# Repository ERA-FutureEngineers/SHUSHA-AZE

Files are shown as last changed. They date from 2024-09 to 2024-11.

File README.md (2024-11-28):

# SHUSHA-AZE 2024
 ## Topics

* [Electronic-Components](#components)
   * [Pixy2.1 cam](#components)
   * [MPU6050](#Gyro)
   * [Servo](#servo)
   * [Driver L298N and Dc motors](#driver)
   * [Ultrasonic sensors](#ultrasonics)
   * [Arduino Mega 2560 Rev3](#mega)
   * [Power Managament](#power)
* [Robot Photos](#robotphotos)
* [Performance videos](#pvideo)
* [Scheme](#scheme)
* [TeamPhoto](#tphoto)
* [Steering system](#system)
* [Logic of Codes](#code)
  * [First round logic](#code)
  * [Second round logic](#code2nd)

## Electronic-Components 
### Pixy2.1 cam  
   
pixy222

The main reason we chose the Pixy 2.1 is its high performance and real-time processing capabilities. Initially, we considered using the ESP CAM, but after discovering its limited image processing capabilities and noticeable latency, we decided to switch to the Pixy 2.1. Pixy 2.1 is a specialized image processing sensor designed for recognizing colors and tracking objects. It can also integrate with various programming platforms and is easily connectable to Arduino, Raspberry Pi, STM32, and other microcontrollers. Moreover, Pixy 2.1 can simultaneously perform multiple object recognition and tracking functions, making it highly convenient for our needs. Another advantage of this camera is its user-friendly interface. It supports numerous communication protocols, such as USB, UART, I2C, and SPI, allowing seamless integration with any microcontroller and other electronic components. Therefore, choosing Pixy 2.1 has enabled our robot to achieve more precise and faster image processing.

#### With this code measure distance

```ino
#include <Pixy2.h>
#include <Servo.h>

Servo servo_9;
long duration;
int distance;
 float knownWidth = 5.0;
 float focalLength = 218; 
 int colorX = 0;
Pixy2 pixy;

void setup() {
  servo_9.attach(2);
  Serial.begin(9600);
  pixy.init();
}

void loop() {
  pixy.ccc.getBlocks();
  
  if (pixy.ccc.numBlocks) {
    int objectWidth = pixy.ccc.blocks[0].m_width; 
    int colorX = pixy.ccc.blocks[0].m_x;
    
    float distance = (knownWidth * focalLength) / objectWidth;
    Serial.println(distance);
    delay(50);
  }
}
```

#### Passing cubes with pixy

```ino
        pixy.ccc.getBlocks();
    bool greenDetected = false, redDetected = false;  
    int colorX = 0, k = 0, j = 0, old = 0, mx = 0;
    height = 0;
    for (int i = 0; i < pixy.ccc.numBlocks; i++) {
      if(old <= (pixy.ccc.blocks[i].m_x) * (pixy.ccc.blocks[i].m_height)){
        old = (pixy.ccc.blocks[i].m_x) * (pixy.ccc.blocks[i].m_height);
        j = i;
      }
    }
      if (pixy.ccc.blocks[j].m_signature == 1) {
        greenDetected = true;
        colorX = pixy.ccc.blocks[j].m_x;
        objectWidth = pixy.ccc.blocks[j].m_width;
        height = pixy.ccc.blocks[j].m_height;
      }
      if (pixy.ccc.blocks[j].m_signature == 2) {
        redDetected = true;
        colorX = pixy.ccc.blocks[j].m_x;
        objectWidth = pixy.ccc.blocks[j].m_width;
        height = pixy.ccc.blocks[j].m_height;
      }

    distance = (knownWidth * focalLength) / objectWidth;

  if (redDetected) {
    if ((R == 1 && abs(currentAngle - targetAngle) <= 50) || L == 1) {
        updateGyroAngle();
        last_color = 2;

        if (colorX > 90) {
            servo_9.write(70);
        } else if (R == 1 && colorX < 40 && abs(currentAngle - targetAngle) >= 15) {
            servo_9.write(110);
        } else {
            servo_9.write(90);
      }
    }
  }
  else if (greenDetected) {
    if ((L == 1 && abs(currentAngle - targetAngle) <= 50) || R == 1) {
        updateGyroAngle();
        last_color = 1;

        if (colorX < 220) {
            servo_9.write(110);
        } else if (L == 1 && colorX > 270 && abs(currentAngle - targetAngle) >= 15) {
            servo_9.write(70);
        } else {
            servo_9.write(90);
        }
      }
    }
```
    
### MPU6050 

mpu222

To use the gyro sensor, we first need to include the **MPU6050.h** library in the project. This library is essential for managing the functions of the MPU6050 sensor and reading its data. 
After powering on the robot, we allocate an initial 5-second time interval to ensure the sensor operates accurately. During this time, the sensor performs proper self-calibration and minimizes potential errors. As a result, obtaining accurate data from the sensor ensures improved performance and precise control of the robot.

#### This code is for measuring degrees with gyro.
```ino
void updateGyroAngle() {
  int16_t gz;
  unsigned long currentTime = millis();
  float deltaTime = (currentTime - previousTime) / 1000.0;
  previousTime = currentTime;

  gz = gyro.getRotationZ();

  float rotationZ = (gz / 131.0) - offsetZ;
  currentAngle += rotationZ * deltaTime;

  Serial.print("Filtered Angle (Yaw): ");
  Serial.println(currentAngle);

```

#### Centering the robot with gyro
```ino
void Gyro() {
  if (currentAngle - 5 > targetAngle) {
    servo_9.write(90 - angle);
  } else if (currentAngle + 5 < targetAngle) {
    servo_9.write(90 + angle);
  } else {
    servo_9.write(90);
  }
  updateGyroAngle();
}
```

### Driver L298N and Dc motors 

driverl298n-222
dc-motors222

In our project, we used the **L298N motor driver** and two DC gear motors. This driver works well with DC motors and does not cause any issues in our project.The L298N provides an effective solution for controlling the rotation direction of the motors and delivering the required power. It helps control the motors quickly and reliably.

#### Code for turning the robot on
```ino
#define LEFT_MOTOR_PWM 5
#define RIGHT_MOTOR_PWM 6
#define LEFT_MOTOR_DIR1 14
#define LEFT_MOTOR_DIR2 15
#define RIGHT_MOTOR_DIR1 16
#define RIGHT_MOTOR_DIR2 17

void setup() {
  pinMode(LEFT_MOTOR_PWM, OUTPUT);
  pinMode(RIGHT_MOTOR_PWM, OUTPUT);
  pinMode(LEFT_MOTOR_DIR1, OUTPUT);
  pinMode(LEFT_MOTOR_DIR2, OUTPUT);
  pinMode(RIGHT_MOTOR_DIR1, OUTPUT);
  pinMode(RIGHT_MOTOR_DIR2, OUTPUT);

  moveForward(70);
}

void loop() {
}

void moveForward(int speed) {
  digitalWrite(LEFT_MOTOR_DIR1, HIGH);
  digitalWrite(LEFT_MOTOR_DIR2, LOW);
  digitalWrite(RIGHT_MOTOR_DIR1, HIGH);
  digitalWrite(RIGHT_MOTOR_DIR2, LOW);
  analogWrite(LEFT_MOTOR_PWM, speed);
  analogWrite(RIGHT_MOTOR_PWM, speed);
}
```

### Servo  

servo222

#### Servo code 

This code takes the angle from the gyroscope and uses it to keep the robot balanced with a servo.
```ino
void updateGyroAngle() {
  int16_t gz, ax, ay, az;
  unsigned long currentTime = millis();
  float deltaTime = (currentTime - previousTime) / 1000.0;
  previousTime = currentTime;

  gz = gyro.getRotationZ();

  float rotationZ = (gz / 131.0) - offsetZ;
  if(abs(rotationZ * deltaTime) >= 0.1)
  currentAngle += rotationZ * deltaTime;

  Serial.print("Filtered Angle (Yaw): ");
  Serial.println(currentAngle);
}

void Gyro() {
  if (currentAngle - 5 > targetAngle) {
    servo_9.write(90 - angle);
  } else if (currentAngle + 5 < targetAngle) {
    servo_9.write(90 + angle);
  } else {
    servo_9.write(90);
  }
  updateGyroAngle();
}
```

The turning system of our robot is implemented through the combined operation of a servo and a gyro sensor. The gyro sensor measures the robot's turning angle and direction changes during movement and sends precise data to the servo. Based on this data, the servo operates accurately, ensuring the robot's turning is executed with greater precision.

### Ultrasonic sensors 
  
ultra-s222

#### Distance measurement code
```ino
const int leftTrigPin = A6;
const int leftEchoPin = A7;
const int rightTrigPin = A0;
const int rightEchoPin = A1;

long getDistance(int trigPin, int echoPin) {
  digitalWrite(trigPin, LOW);
  delayMicroseconds(2);
  digitalWrite(trigPin, HIGH);
  delayMicroseconds(10);
  digitalWrite(trigPin, LOW);

  long duration = pulseIn(echoPin, HIGH);
  long distance = duration * 0.034 / 2;

  return distance;
}

void setup() {
  pinMode(leftTrigPin, OUTPUT);
  pinMode(leftEchoPin, INPUT);
  pinMode(rightTrigPin, OUTPUT);
  pinMode(rightEchoPin, INPUT);
  Serial.begin(9600);
}

void loop() {
  long leftDistance = getDistance(leftTrigPin, leftEchoPin);
  long rightDistance = getDistance(rightTrigPin, rightEchoPin);
  Serial.print(leftDistance);
  Serial.print(" cm, Right: ");
  Serial.print(rightDistance); 
  Serial.println(" cm");
  delay(10);
}
```

### Arduino Mega 2560 Rev3 

mega222

Initially, we used an Arduino Uno in our robot. However, as the project developed, the number of sensors increased, and the pins on the Uno were no longer sufficient. For this reason, we decided to switch to the Arduino Mega. Compared to the Uno, the Mega offers significantly more capabilities. For instance, the Uno has only 14 digital input/output pins and 6 analog input pins, whereas the Mega provides 54 digital input/output pins and 16 analog input pins. These additional pins allow for connecting more sensors. In addition, the Mega has more memory (32 KB on the Uno versus 256 KB on the Mega) and a more powerful processor. Switching to the Mega was crucial for the robot’s development, as its additional pins and higher performance make it possible to manage more complex systems. Therefore, the Arduino Mega proved to be a more suitable choice for our robot.

### Power Managament 

battery555
bat2

In our robot, we use cylindrical Lithium Polymer 3.7V 18650 rechargeable Li-ion batteries as the power source. By combining three batteries, we obtain approximately 11V of power. This voltage is connected to the motor driver, and the driver’s output provides the 5V needed for the proper operation of the sensors. Since each battery weighs only 47.5 grams, the robot remains lightweight and can move faster. These batteries offer both an efficient and practical solution.

### Robot Photos 

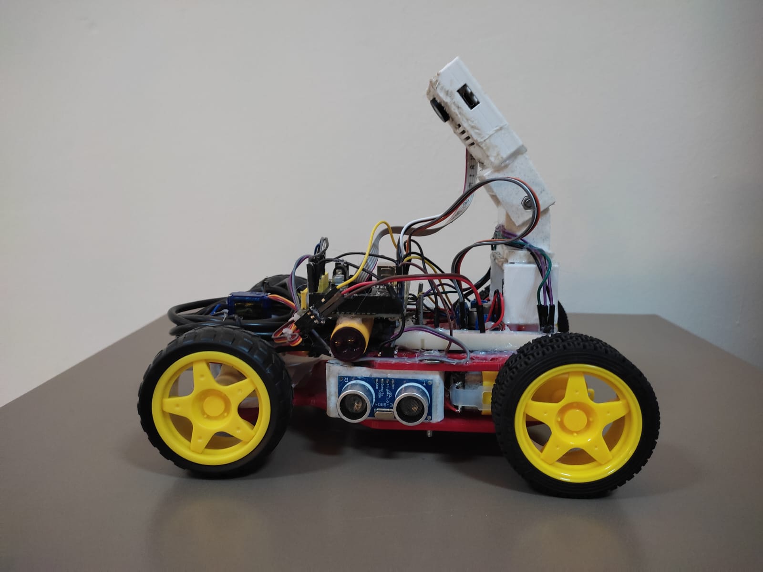
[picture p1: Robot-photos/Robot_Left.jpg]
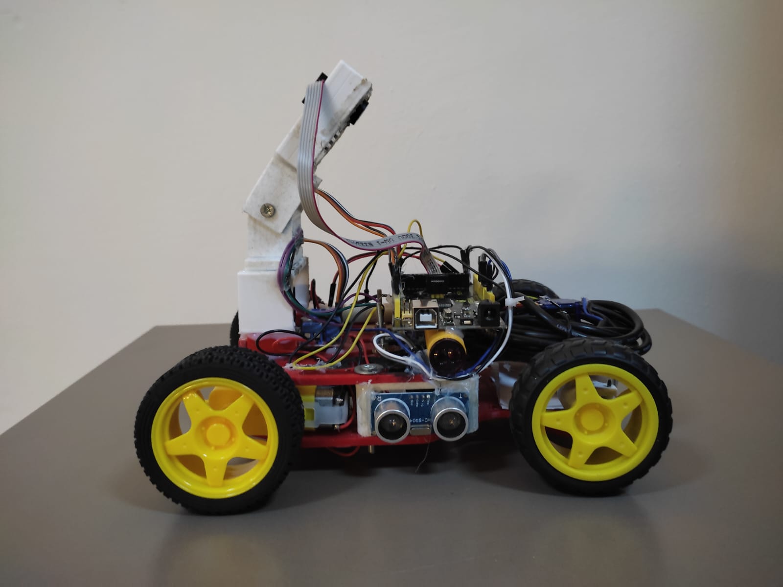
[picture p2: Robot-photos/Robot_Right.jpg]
|  |  | 
| :--: | :--: |
| *Left* | *Right* |
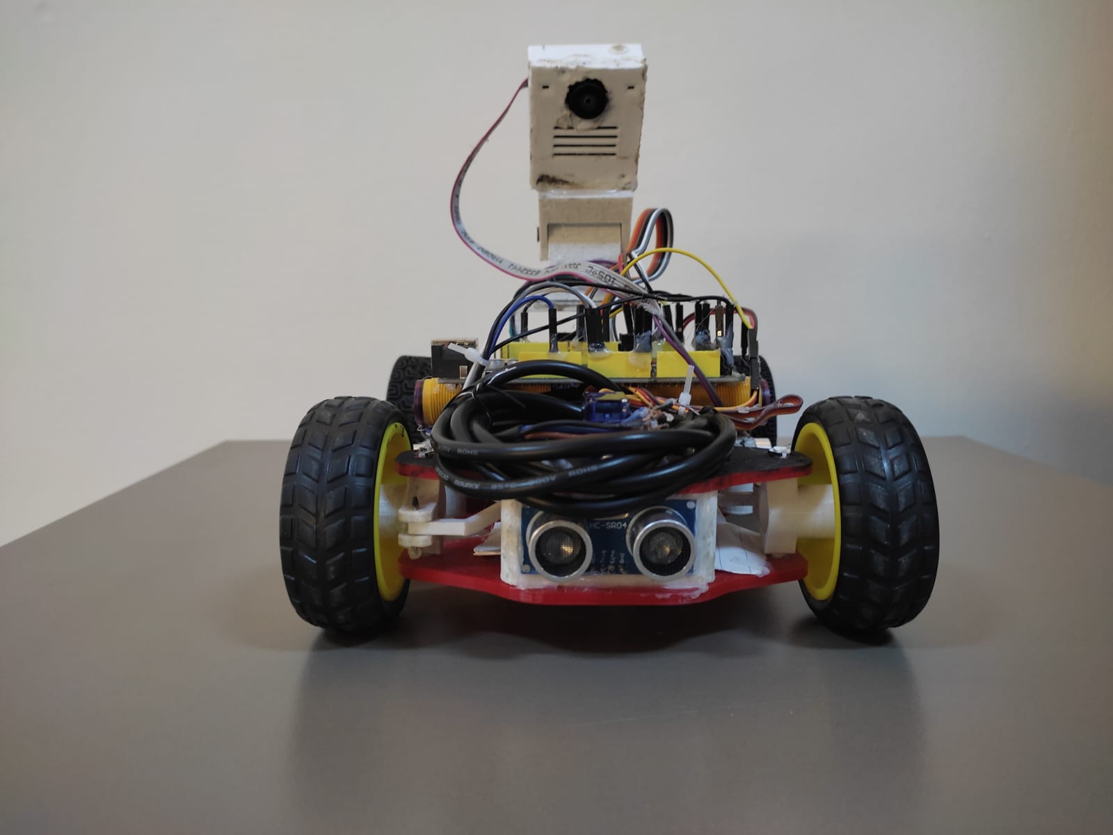
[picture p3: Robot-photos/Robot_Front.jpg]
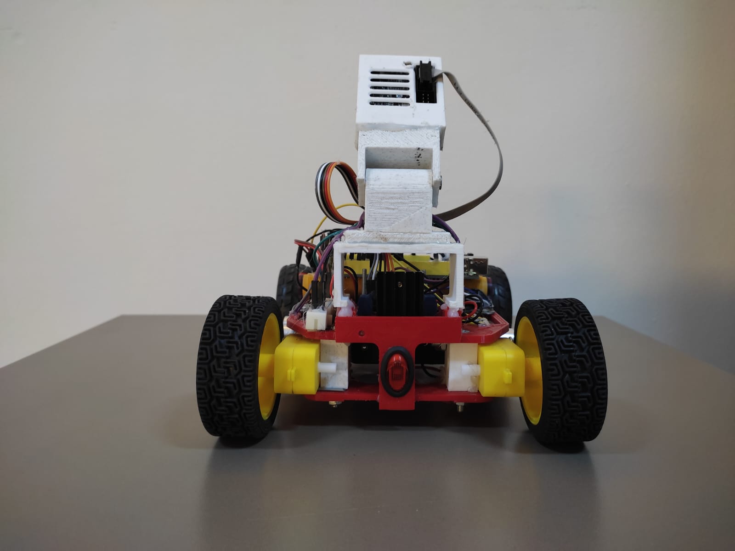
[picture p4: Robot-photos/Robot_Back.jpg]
|  |  | 
| *Front* | *Back* |
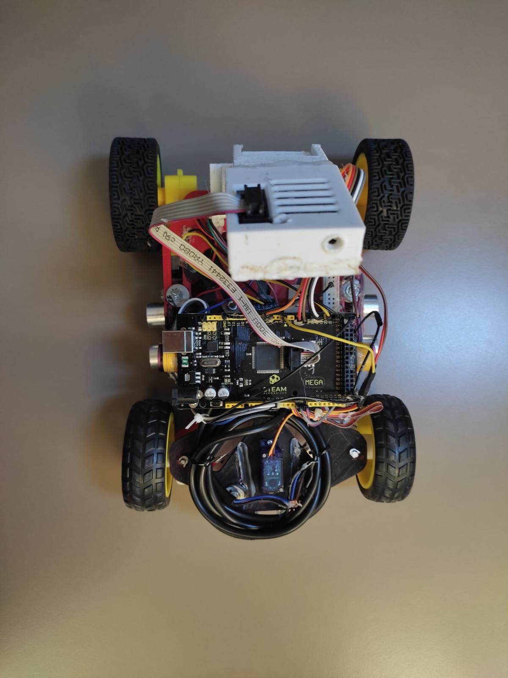
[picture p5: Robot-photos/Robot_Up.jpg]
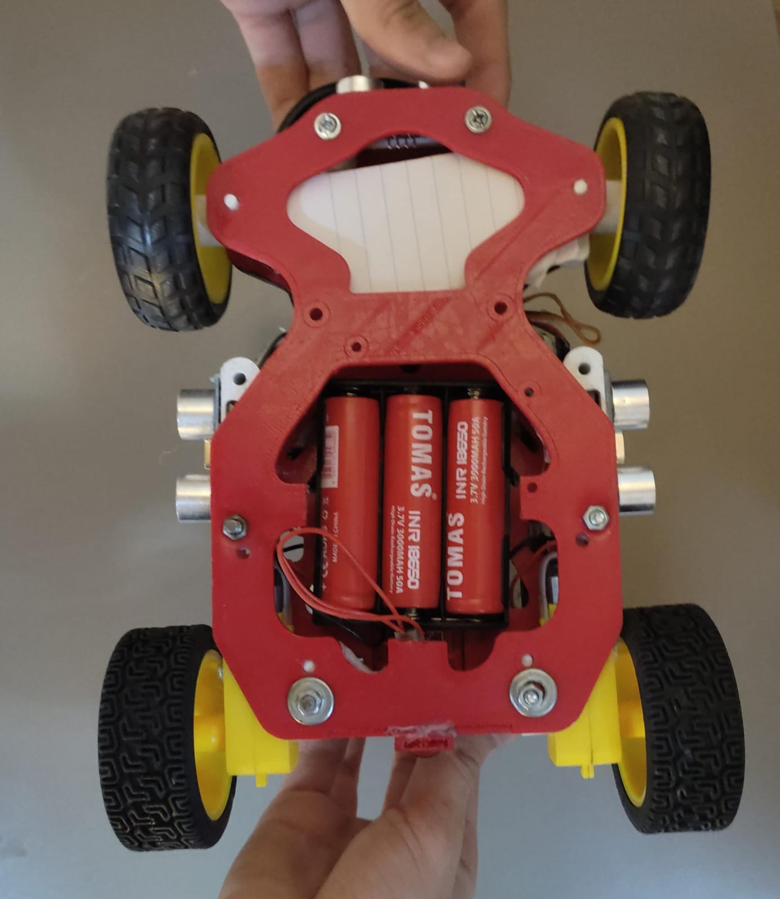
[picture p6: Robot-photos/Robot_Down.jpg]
|  |  | 
| *Up* | *Down* |

### Scheme 

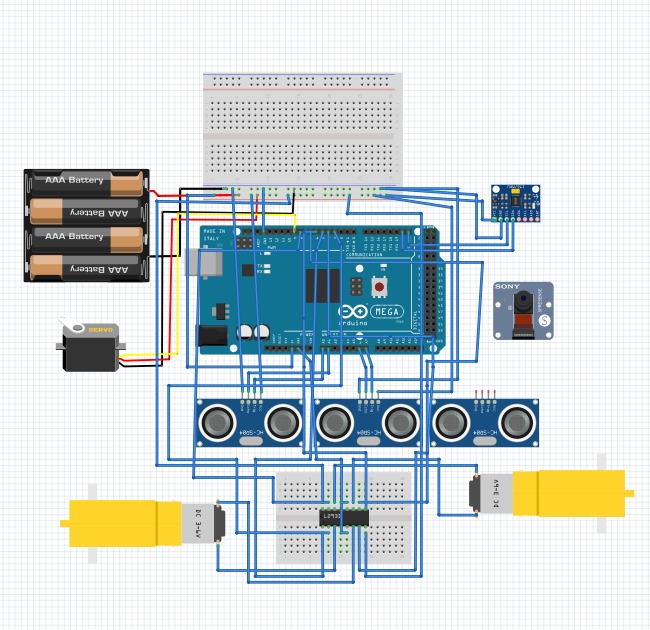
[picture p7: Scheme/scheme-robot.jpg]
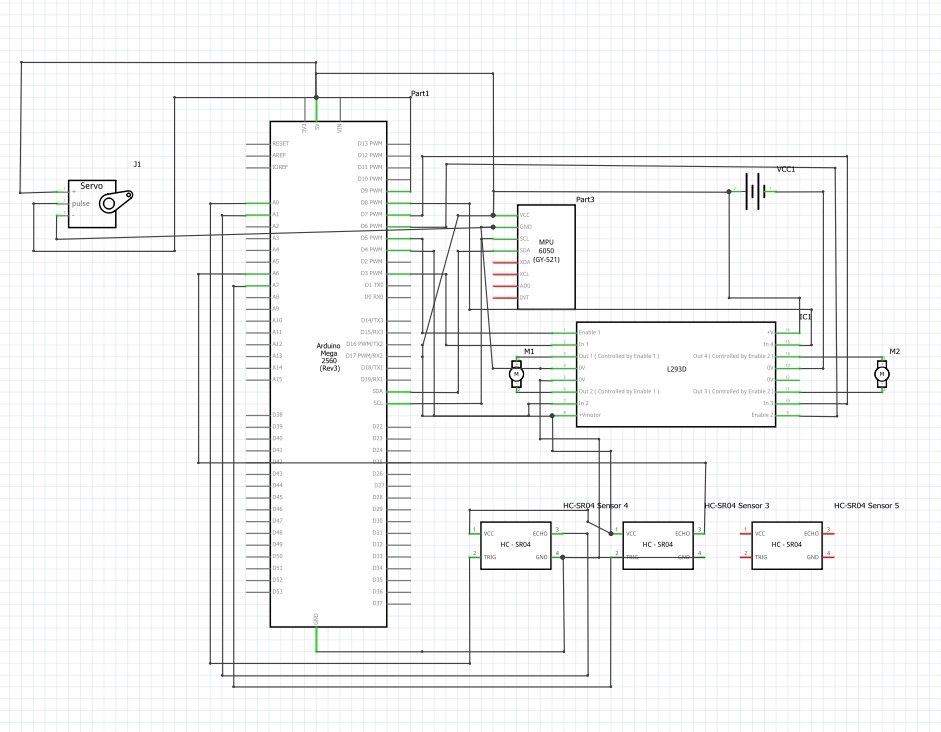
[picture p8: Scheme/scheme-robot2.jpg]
|  |  | 
| :--: | :--: |
| *Scheme* | *Circuit diagram* |

### Performance videos of our robot 

 **First raund performance video**-[Youtube](https://youtu.be/xtTiP2OPR9s)
 
 **Second raund test code**-[Youtube](https://youtu.be/_AvwfRnpVDk)

### TeamPhoto 

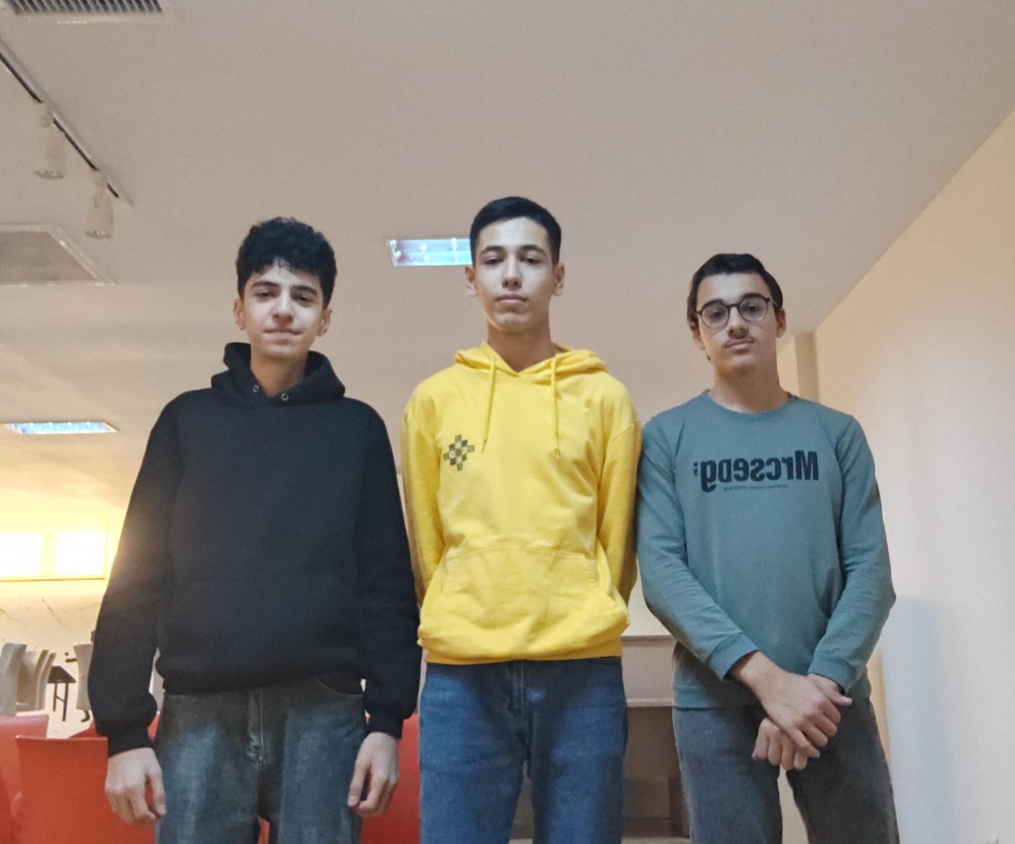
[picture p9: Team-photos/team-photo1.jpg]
|  |
| :--: | 
| *Team Photo* | 

### Steering system 

steerin servo

In this design, we have illustrated the robot's steering system. At the center of the system is a servo motor that controls a linkage mechanism responsible for steering the wheels in both directions. The linkage rods are designed to turn the wheels left or right based on the rotation angle of the servo motor. The wheels are mounted to the robot chassis using strong and durable attachment points that support the system. This mechanism is ideal for precise steering and provides high maneuverability thanks to the quick response of the servo motor.

## Codes 

### First round code logic 

Immediately after connecting the robot, we turn on the gyro in the code and the gyro begins to measure the angle. First of all, we need to know in which direction the robot is going. Accordingly, we wrote in the code that if one of the ultrasonic sensors sees a distance of more than 80 cm, it means that it has reached the edge. We call this a decision, and the decision is repeated only once after the robot is connected. For example, if the right ultrasonic distance is more than 80 cm, it means that we are going in a clockwise direction. Otherwise, if the left sensor measures the distance above 80 cm, it means that we are going counter-clockwise. The ultrasonic sees above 80cm and the servo turns the robot until the gyro is 90 degrees. This counter is necessary so that we know that we have finished the 3rd round. If the ultrasonic sensors counts the edges 12 times, it means that we have already finished the 3rd round and the robot goes for a second and stops. This is the logic of the first round.

### Second round code logic 

After the robot started, the gyro keeps the robot centered until it reaches the first turn (as we did in the first round, there's decision-making here). We know the direction the robot has turned. We’ve created a counter to track when the robot completes the third loop. As soon as the robot reaches the turn, the gyro turns 90 degrees, and we increment the counter by 1. The gyro keeps the robot centered until it detects a cube with the camera. When the camera detects a cube, we know the robot is either to the left or right of the cube based on the **X** coordinate. If the cube is far away, the robot does not approach the cube, but instead, continues operating based on the gyro data by checking the **Z** coordinate. If the camera detects a red cube, the robot passes to the right of it based on the coordinates, and if it detects a green cube, the robot passes to the left of it.When the counter reaches 8 and the last cube seen was red, the gyro’s target angle is decreased by 180 degrees. The robot finishes by parking after completing the third loop.

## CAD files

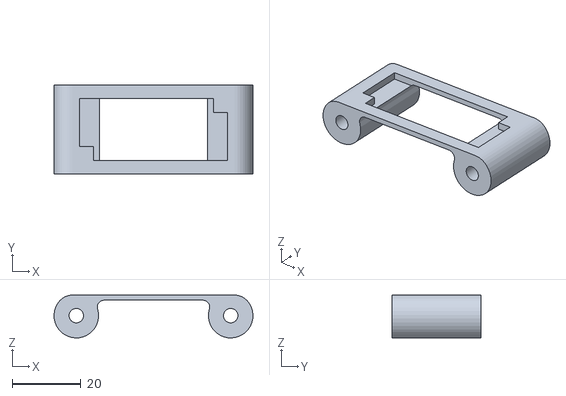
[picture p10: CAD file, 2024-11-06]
Design/Frontal.STL
58.0 x 26.0 x 12.5

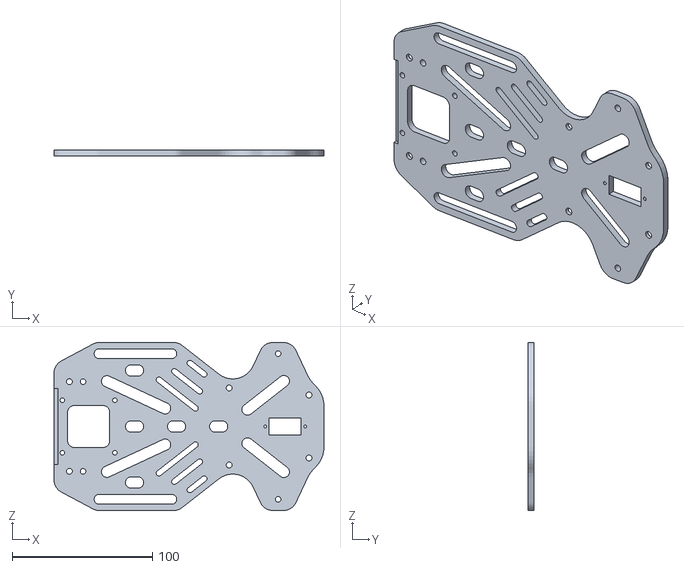
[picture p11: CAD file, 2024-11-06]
Design/Chassis_UP.STL
192.7 x 4.00 x 120.0

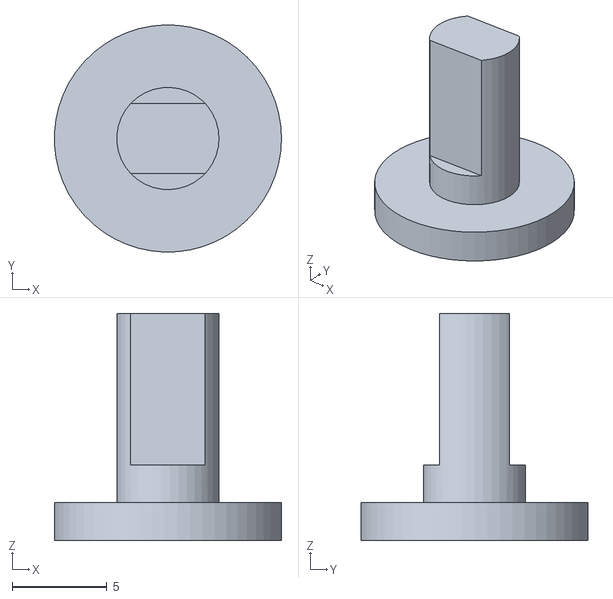
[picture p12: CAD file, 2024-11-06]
Design/driveshaft_front.STL
12.0 x 12.0 x 12.0

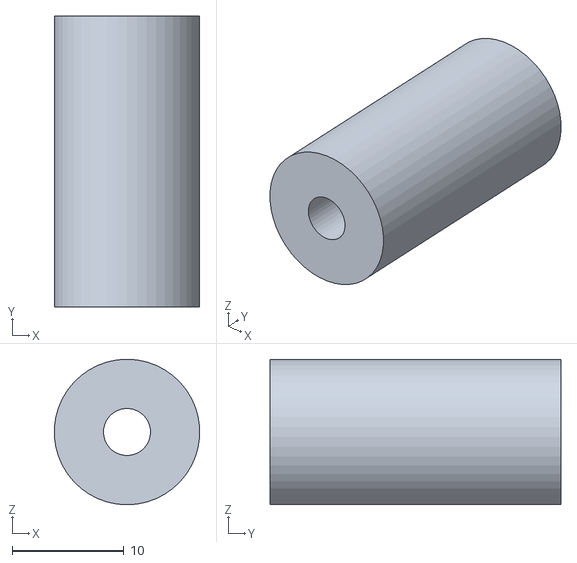
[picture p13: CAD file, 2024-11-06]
Design/spacer.STL
13.0 x 26.0 x 13.0

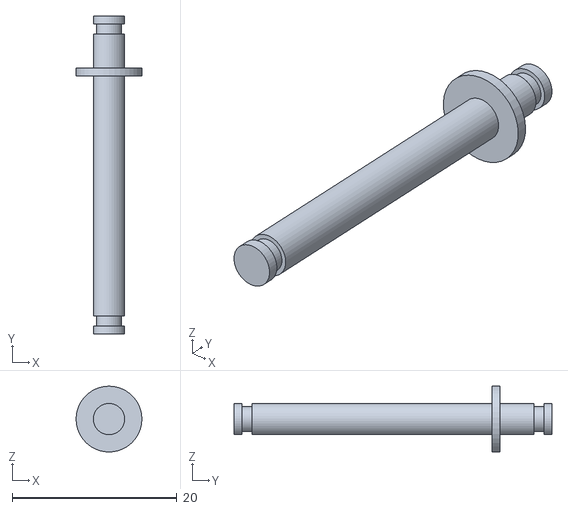
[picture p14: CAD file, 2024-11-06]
Design/pivot_hub.STL
7.99 x 38.6 x 7.99

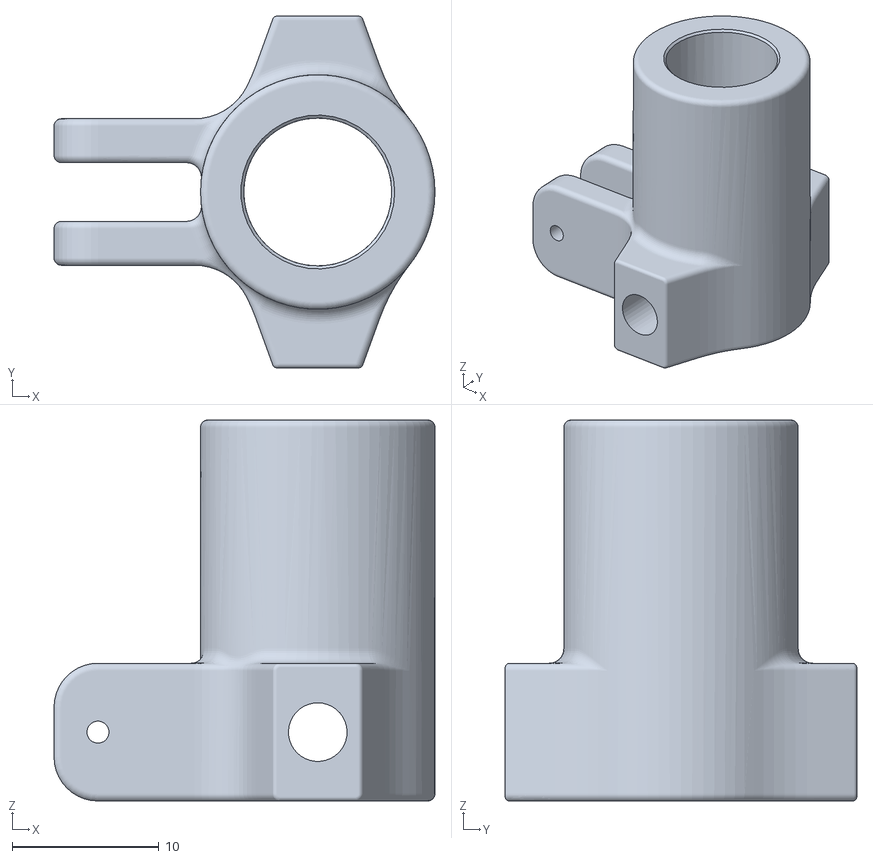
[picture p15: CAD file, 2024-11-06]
Design/Hub_front.STL
26.0 x 24.0 x 26.0

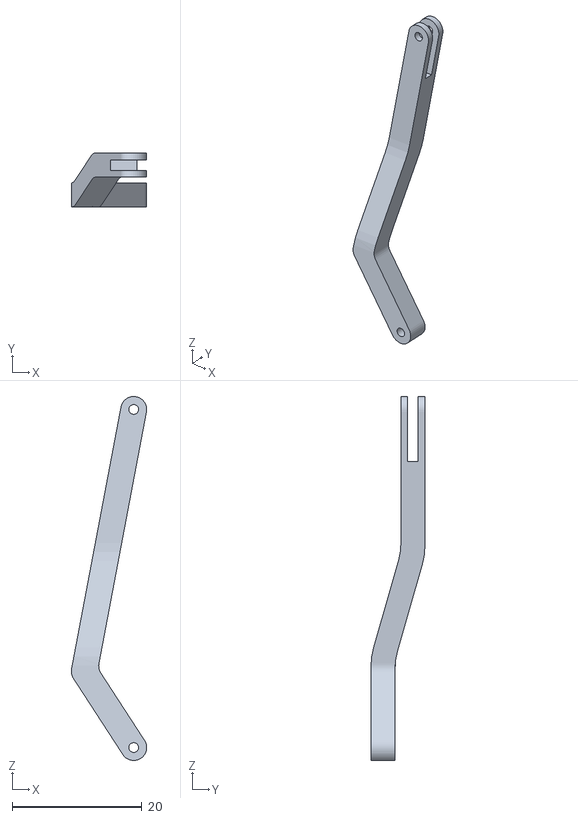
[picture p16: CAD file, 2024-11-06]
Design/steering_bar.STL
11.6 x 8.30 x 56.1

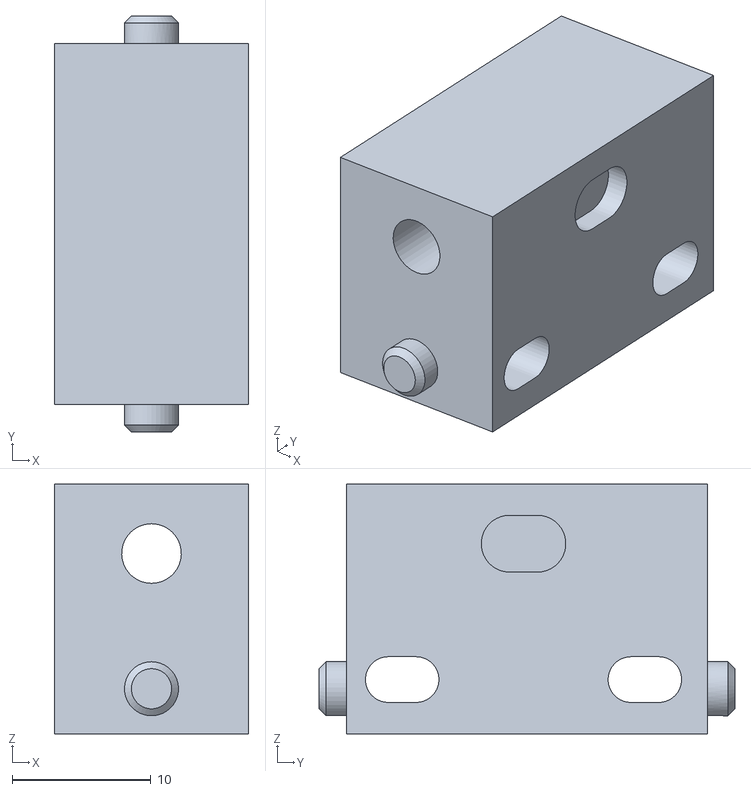
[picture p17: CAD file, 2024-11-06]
Design/wheelmotor_support.STL
14.0 x 30.0 x 18.0

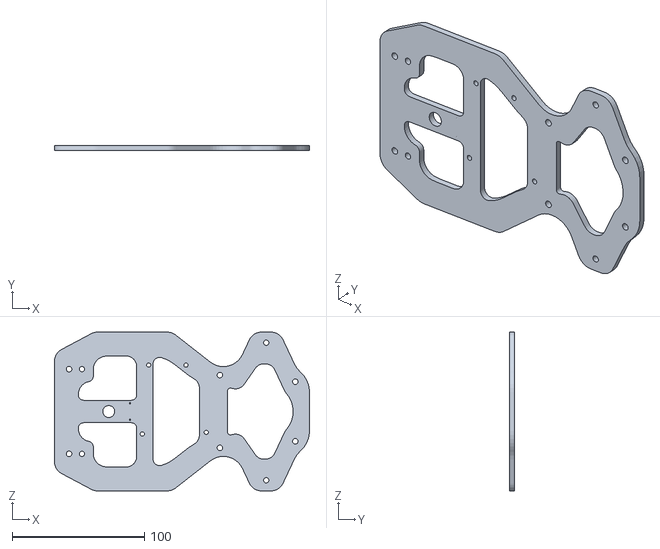
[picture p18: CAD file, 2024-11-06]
Design/Chassis_DOWN.STL
192.7 x 4.00 x 120.0

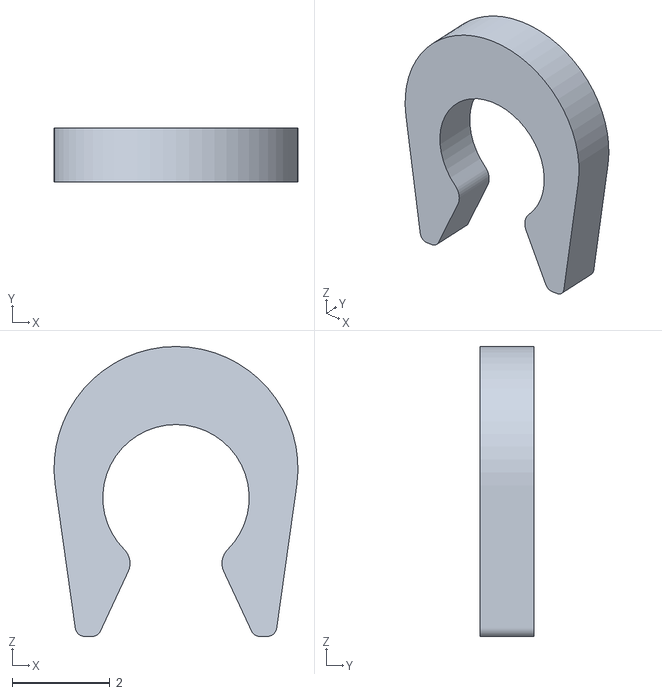
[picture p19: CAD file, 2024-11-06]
Design/seeger.STL
5.00 x 1.10 x 5.94

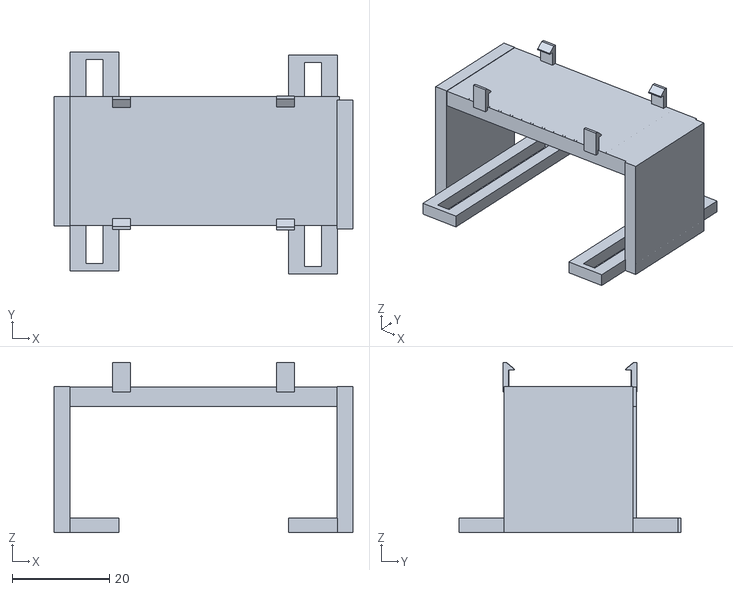
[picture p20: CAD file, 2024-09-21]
Design/support.stl
61.5 x 45.6 x 35.0

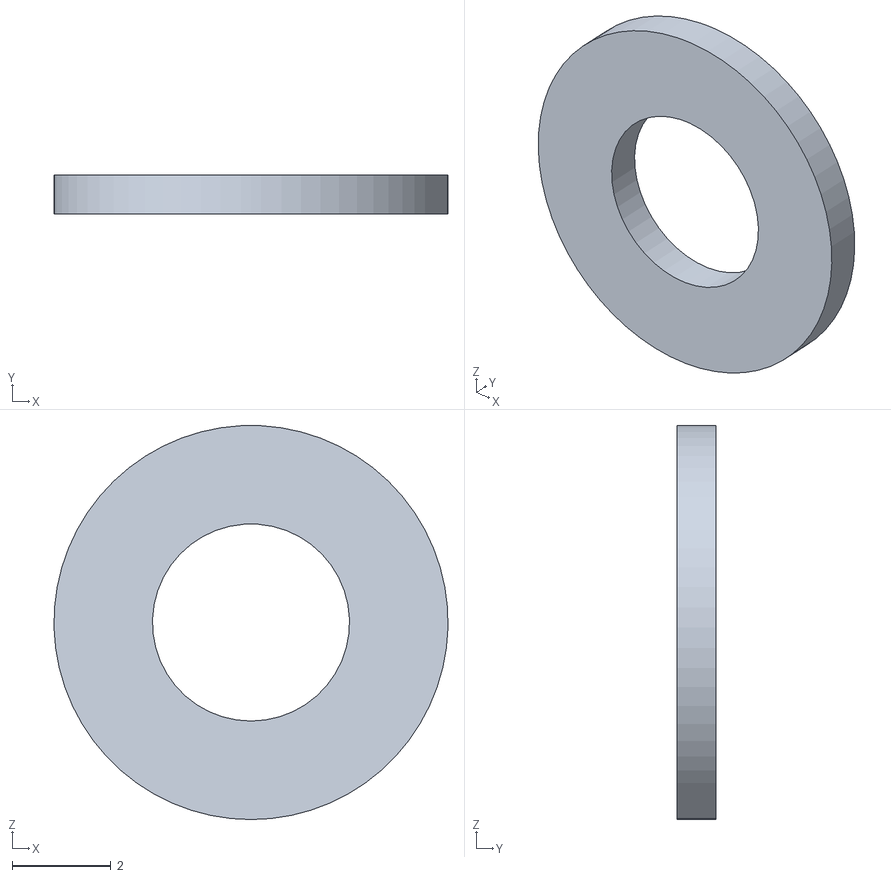
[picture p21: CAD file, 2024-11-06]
Design/washer.STL
8.00 x 0.8 x 8.00

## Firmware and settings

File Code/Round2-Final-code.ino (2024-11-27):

#include <Servo.h>
#include <Pixy2.h>
#include <Wire.h>
#include <MPU6050.h>

Servo servo_9;
Pixy2 pixy;
MPU6050 gyro;

float frontdist = 0, rightdist = 0, leftdist = 0;
int objectWidth = 0;
float knownWidth = 5.0, focalLength = 200, distance = 0;
bool colorDetected = false;
float targetAngle = 0;
float currentAngle = 0;
float offsetZ = 0;
int angle = 20;
float previousRotationZ = 0.0;
int colorX = 0;
int target = 30, L = 0, R = 0, old = 0, j = 0, count = 0, last_color = 0, old_last_color = 0, reverse = 0, height = 0, old1 = 1, old2 = 1, old3 = 1, secondcount = 0, second = 3000, gyro_count = 0;
   bool greenDetected = false, redDetected = false;

long readUltrasonicDistance(int triggerPin, int echoPin) {
  pinMode(triggerPin, OUTPUT);
  digitalWrite(triggerPin, LOW);
  delayMicroseconds(2);
  digitalWrite(triggerPin, HIGH);
  delayMicroseconds(10);
  digitalWrite(triggerPin, LOW);
  pinMode(echoPin, INPUT);
  return pulseIn(echoPin, HIGH);
}

unsigned long previousMillis = 0;
unsigned long previousTime;
unsigned long previousPixyMillis = 0;
unsigned long previousGyroMillis = 0;
const unsigned long pixyInterval = 100;
const unsigned long gyroInterval = 10;
unsigned long CautionMillis = 0;
unsigned long PreviousCautionMillis = 0;

void setup() {
  Serial.begin(9600);
  Wire.begin();
  Wire.setClock(400000);
  gyro.initialize();
  servo_9.attach(2);
  pixy.init();

  if (!gyro.testConnection()) {
    Serial.println("MPU6050 connection failed.");
    while (1);
  }

  servo_9.write(90);
  calibrateGyro();
  
  pinMode(6, OUTPUT);
  pinMode(5, OUTPUT);
  pinMode(16, OUTPUT);
  pinMode(15, OUTPUT);
  pinMode(17, OUTPUT);
  pinMode(14, OUTPUT);
  analogWrite(5, 65);
  analogWrite(6, 65);
  digitalWrite(14, HIGH);
  digitalWrite(16, HIGH);
  digitalWrite(15, LOW);
  digitalWrite(17, LOW);

  previousTime = millis();
}

void loop() {
  if (L == 0 && R == 0) {
    MeasureDistance();
    if (rightdist > 80) {
      R = 1;
    } else if (leftdist > 80) {
      L = 1; 
    }
  unsigned long currentMillis = millis();
  if (currentMillis - previousGyroMillis >= gyroInterval) {
    previousGyroMillis = currentMillis;
    Gyro();
    }
  }

  if(R == 1 or L == 1){
    servo_9.write(90);
    Stop();
    delay(500);
    Backward();    
    CautionMillis = millis();
    PreviousCautionMillis = millis();
    while(CautionMillis - PreviousCautionMillis <= 1000){
    CautionMillis = millis();
    updateGyroAngle();
    }
    Forward();
  }

  while (L == 1 || R == 1) {
    pixy.ccc.getBlocks();
    bool parkingDetected = false;  
    greenDetected = false, redDetected = false;
    int k = 0, j = 0, old = 0, mx = 0;
    colorX = 0;
    height = 0;
    for (int i = 0; i < pixy.ccc.numBlocks; i++) {
      if(old <= (pixy.ccc.blocks[i].m_height)){
        old = (pixy.ccc.blocks[i].m_height);
        j = i;
      }
    }
      if(count >= 4 and pixy.ccc.blocks[j].m_signature == 3){
      parkingDetected = true;
      Parking();
      }

      if (pixy.ccc.blocks[j].m_signature == 1) {
        greenDetected = true;
        colorX = pixy.ccc.blocks[j].m_x;
        objectWidth = pixy.ccc.blocks[j].m_width;
        height = pixy.ccc.blocks[j].m_height;
      }
      if (pixy.ccc.blocks[j].m_signature == 2) {
        redDetected = true;
        colorX = pixy.ccc.blocks[j].m_x;
        objectWidth = pixy.ccc.blocks[j].m_width;
        height = pixy.ccc.blocks[j].m_height;
      }

    MeasureDistance();
    distance = (knownWidth * focalLength) / objectWidth;
      if (rightdist <= 5) {
        while(rightdist <= 10){
        servo_9.write(115);
        rightdist = 0.01723 * readUltrasonicDistance(A0, A1);
        delay(10);
        }
      }
      if (leftdist <= 5) {
        while(leftdist <= 10){
        servo_9.write(65);
        leftdist = 0.01723 * readUltrasonicDistance(A6, A7);
        delay(10);
        }
      }

    unsigned long currentMillis = millis(); 
    if (currentMillis - previousMillis >= 3000 && leftdist >= 100 && rightdist < 100 and L == 1) { 
      previousMillis = currentMillis;
      targetAngle += 89.5;
      angle = 30;
      count++;
    }

    if (currentMillis - previousMillis >= 3000 && rightdist >= 100 && leftdist < 100 and R == 1) { 
      previousMillis = currentMillis;
      targetAngle -= 90.5;
      angle = 30;
      count++;
    }

    if (abs(currentAngle - targetAngle) <= 10) {
      angle = 20;
    }
    if(greenDetected or redDetected)
    ColorSearching();
    else 
    Gyro();
  }
}

void Forward() {
  analogWrite(6, 65);
  analogWrite(5, 65);
  digitalWrite(14, HIGH);
  digitalWrite(16, HIGH);
  digitalWrite(15, LOW);
  digitalWrite(18, LOW);
}

void Backward() {
  analogWrite(6, 75);
  analogWrite(5, 75);
  digitalWrite(15, HIGH);
  digitalWrite(18, HIGH);
  digitalWrite(14, LOW);
  digitalWrite(16, LOW);
}

void Stop() {
  analogWrite(6, 0);
  analogWrite(5, 0);
}

void Move() {
  analogWrite(6, 65);
  analogWrite(5, 65);
}

void MeasureDistance() {
  leftdist = 0.01723 * readUltrasonicDistance(A6, A7);
  delay(10);
  rightdist = 0.01723 * readUltrasonicDistance(A0, A1);
  delay(10);
  // frontdist = 0.01723 * readUltrasonicDistance(A4, A5);
  // delay(10);  
}

void updateGyroAngle() {
  int16_t gz, ax, ay, az;
  unsigned long currentTime = millis();
  float deltaTime = (currentTime - previousTime) / 1000.0;
  previousTime = currentTime;

  gz = gyro.getRotationZ();

  float rotationZ = (gz / 131.0) - offsetZ;
  currentAngle += rotationZ * deltaTime;

  Serial.print("Filtered Angle (Yaw): ");
  Serial.println(currentAngle);
}

void Gyro() {
  int deadzone = 5;
  if (currentAngle > targetAngle + deadzone) {
    servo_9.write(90 - angle);
  } else if (currentAngle < targetAngle - deadzone) {
    servo_9.write(90 + angle);
  } else {
    servo_9.write(90);
  }
  updateGyroAngle();
}


void calibrateGyro() {
  int numReadings = 200;
  long totalZ = 0;

  for (int i = 0; i < numReadings; i++) {
    gyro.getRotationZ();
    delay(10);
  }

  for (int i = 0; i < numReadings; i++) {
    int16_t gz = gyro.getRotationZ();
    totalZ += gz;
    delay(10);
  }

  offsetZ = totalZ / (float)numReadings / 131.0;
  Serial.print("Gyroscope Z-axis offset: ");
  Serial.println(offsetZ);
}

void ColorSearching() {
  if (redDetected) {
    if ((R == 1 && abs(currentAngle - targetAngle) <= 35) || L == 1) {
        updateGyroAngle();
        last_color = 2;

        if (colorX > 50) {
            servo_9.write(65);
        } else if (R == 1 && colorX < 10 && abs(currentAngle - targetAngle) >= 10) {
            servo_9.write(115);
        } else {
            servo_9.write(90);
      }
    }
    else
    Gyro();
  }
  else if (greenDetected) {
    if ((L == 1 && abs(currentAngle - targetAngle) <= 35) || R == 1) {
        updateGyroAngle();
        last_color = 1;
        if (colorX < 230) {
            servo_9.write(115);
        } else if (L == 1 && colorX > 260 && abs(currentAngle - targetAngle) >= 10) {
            servo_9.write(65);
        } else {
            servo_9.write(90);
        }
      }
      else
      Gyro();
    }
}

// void ReverseTurning() {
//     if(last_color == 2 and count == 8 and reverse == 0){
//       while(abs(currentAngle - targetAngle) >= 5){
//         Gyro();
//       }
//       angle = 25;
//       Backward();
//       targetAngle += 90;
//       analogWrite(5, 70);
//       analogWrite(6, 70);
//       while(abs(currentAngle - targetAngle) >= 5){
//         servo_9.write(60);
//         updateGyroAngle();
//       }
//       servo_9.write(90);
//       delay(500);
//       Forward();      
//       analogWrite(5, 65);
//       analogWrite(6, 65);
//       angle = 20;
//       if(L == 1){R = 1; L = 0;}
//       else if(R == 1){L = 1; R = 0;}
//       count = 100;
//       targetAngle += 90;
//     }
//     else if(count == 8)
//     reverse = 1;
// }

void Parking() {
  bool parkingDetected = true;
  secondcount = millis();
  
    unsigned long lastDetectionTime = millis();
    int target = 42, Kp = 1.5, Kd = 0.3, err = 0, errold = 0, U = 0;

    while (parkingDetected) {
      pixy.ccc.getBlocks();
      MeasureDistance();
      int colorX = 0;
      redDetected = false, greenDetected = false;

    for (int i = 0; i < pixy.ccc.numBlocks; i++) {
      if(old <= (pixy.ccc.blocks[i].m_height)){
        old = (pixy.ccc.blocks[i].m_height);
        j = i;
      }
    }
      if (pixy.ccc.blocks[j].m_signature == 1) {
        greenDetected = true;
        colorX = pixy.ccc.blocks[j].m_x;
      }
      if (pixy.ccc.blocks[j].m_signature == 2) {
        redDetected = true;
        colorX = pixy.ccc.blocks[j].m_x;
      }
      if (pixy.ccc.blocks[j].m_signature == 3) {
        lastDetectionTime = millis();
        colorX = pixy.ccc.blocks[j].m_x;
      }

      if (millis() - lastDetectionTime > 1000) {
        parkingDetected = false;
      }

    if(abs(currentAngle - targetAngle <= 20)){
    if(greenDetected or redDetected)
    ColorSearching();
    else if(pixy.ccc.blocks[j].m_signature == 3){
      // if(leftdist >= 50){
      
      // if(R == 1){
      //     if (colorX > 40) {
      //       servo_9.write(65);
      //   } else if (colorX < 10 && abs(currentAngle - targetAngle) >= 10) {
      //       servo_9.write(115);
      //   } else {
      //       servo_9.write(90);
      //   }    
      // }
      // else if(L == 1){
      //     if (colorX < 270) {
      //       servo_9.write(115);
      //   } else if (L == 1 && colorX > 300 && abs(currentAngle - targetAngle) >= 10) {
      //       servo_9.write(70);
      //   } else {
      //       servo_9.write(90);
      //       }      
      //     }
        // }
        // else{
        if(L == 1){
          err = leftdist - target;
          U = err * Kp + Kd * (err - errold);
          if (90 + U > 120) {
          servo_9.write(120);
          }
           else {
          servo_9.write(90 + U);
          }
          errold = err;  
         } 
        }
      }
    else {
      Gyro();
    }

    unsigned long currentMillis = millis(); 
    if(currentMillis - secondcount < 5000){
    if (currentMillis - previousMillis >= 3000 && leftdist >= 100 && rightdist < 100 and L == 1) { 
      previousMillis = currentMillis;
      targetAngle += 90;
      angle = 35;
      count++;
    }

    if (currentMillis - previousMillis >= 3000 && rightdist >= 100 && leftdist < 100 and R == 1) { 
      previousMillis = currentMillis;
      targetAngle -= 90;
      angle = 35;
      count++;
      }
    }
  }
    currentAngle = 0;
    analogWrite(5, 0);
    analogWrite(6, 0);
    delay(500);
    Backward();
    delay(500);
    analogWrite(5, 85);
    analogWrite(6, 85);

    CautionMillis = millis();
    PreviousCautionMillis = millis();
    while(CautionMillis - PreviousCautionMillis <= 1500){
    CautionMillis = millis();
      if(L == 1)
      servo_9.write(125);
      if(R == 1)
      servo_9.write(55);
    }
    servo_9.write(90);
    MeasureDistance();
    Forward();
    analogWrite(5, 60);
    analogWrite(6, 60);

    while (leftdist >= 15 || rightdist >= 15) {
      MeasureDistance();
      pixy.ccc.getBlocks();
      int colorX1 = 0;
      int colorX2 = 0;
      int X0 = 0;
      int X1 = 0;
      if(pixy.ccc.numBlocks == 1){
        servo_9.write(90);
      }
      else if(pixy.ccc.numBlocks == 2){
          colorX1 = pixy.ccc.blocks[0].m_x;
          colorX2 = pixy.ccc.blocks[1].m_x;
          if(colorX1 < colorX2){
            X0 = colorX1;
            X1 = colorX2; 
          }
          else {
            X0 = colorX2;
            X1 = colorX1;             
          }
      }

      if(abs(158 - X0) > abs(158 - X1) + 10)
      servo_9.write(110);
      else if(abs(158 - X0) + 10 < abs(158 - X1))
      servo_9.write(70);
      else 
      servo_9.write(90);
    }

    while (L == 1 or R == 1) {
      servo_9.write(90);
      Stop();
  }
}

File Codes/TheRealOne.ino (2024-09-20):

#include <Servo.h>
#include <Pixy2.h>

Servo servo_9;
Pixy2 pixy;

int g = 0, r = 0;  // Flags to track whether it turned left (green) or right (red)

bool colorDetected = false;
unsigned long lastColorDetectedTime = 0;
const unsigned long detectionTimeout = 500; // Time in milliseconds to confirm object is out of view



long readUltrasonicDistance(int triggerPin, int echoPin) {
  pinMode(triggerPin, OUTPUT);  // Clear the trigger
  digitalWrite(triggerPin, LOW);
  delayMicroseconds(2);
  digitalWrite(triggerPin, HIGH);
  delayMicroseconds(10);
  digitalWrite(triggerPin, LOW);
  pinMode(echoPin, INPUT);
  return pulseIn(echoPin, HIGH);
}

void setup() {
  servo_9.attach(9);          // Attach servo to pin 9
  Serial.begin(9600);         // Initialize serial port for debugging
  pixy.init();                // Initialize Pixy2

  pinMode(6, OUTPUT);
  pinMode(5, OUTPUT);
  pinMode(8, OUTPUT);
  pinMode(4, OUTPUT);
  pinMode(7, OUTPUT);
  pinMode(3, OUTPUT);

  analogWrite(6, 75);         // Turn on motors to move straight
  analogWrite(5, 80);
  digitalWrite(8, HIGH);
  digitalWrite(4, HIGH);

  servo_9.write(80);         // Set initial servo position to 80 degrees
}

void loop() {


    float frontdist = 0.01723 * readUltrasonicDistance(A1, A0);
  float leftdist = 0.01723 * readUltrasonicDistance(12, 13);
  float rightdist = 0.01723 * readUltrasonicDistance(11, 10);

  
  pixy.ccc.getBlocks();       // Get data from Pixy2

  bool greenDetected = false;
  bool redDetected = false;
  int colorX = 0;

  // Check for blocks and track the color position
  if(pixy.ccc.numBlocks > 0){
  for (int i = 0; i < pixy.ccc.numBlocks; i++) {
    if (pixy.ccc.blocks[i].m_signature == 1) {  // Green color
      greenDetected = true;
      colorX = pixy.ccc.blocks[i].m_x;
    }
    if (pixy.ccc.blocks[i].m_signature == 2) {  // Red color
      redDetected = true;
      colorX = pixy.ccc.blocks[i].m_x;
    }
  }

  frontdist = 0.01723 * readUltrasonicDistance(A1, A0);  // Convert to cm

  // Move towards the detected color using servo to steer
  if (greenDetected || redDetected) {
    // Adjust servo to turn towards the color based on its position in the frame
    if (colorX < 140) {
      // Color is on the left side of the camera frame
      servo_9.write(100);  // Turn left (increase servo angle)
    } else if (colorX > 180) {
      // Color is on the right side of the camera frame
      servo_9.write(60);   // Turn right (decrease servo angle)
    } else {
      // Color is centered
      servo_9.write(80);   // Keep servo straight
    }

    // Check if the front distance is less than 20 cm
    if (frontdist < 20) {

      // Perform obstacle avoidance using the servo
      if (greenDetected) {

        digitalWrite(8, LOW);
        digitalWrite(4, LOW);
        delay(1000);
        digitalWrite(7, HIGH);
        digitalWrite(3, HIGH);
        
        servo_9.write(55); 
        delay(2000);

        digitalWrite(8, HIGH);
        digitalWrite(4, HIGH);
        digitalWrite(7, LOW);
        digitalWrite(3, LOW);

        servo_9.write(105);  // Turn left (green)
        delay(1000);         // Hold the turn for 1 second
        servo_9.write(55);   // Reverse the turn
        delay(1000);         // Hold the reverse turn for 1 second
      } else if (redDetected) {
        digitalWrite(8, LOW);
        digitalWrite(4, LOW);
        delay(1000);
        digitalWrite(7, HIGH);
        digitalWrite(3, HIGH);
        servo_9.write(105); 
        delay(2000);

        digitalWrite(8, HIGH);
        digitalWrite(4, HIGH);
        digitalWrite(7, LOW);
        digitalWrite(3, LOW);

        servo_9.write(55);  // Turn left (green)
        delay(1000);         // Hold the turn for 1 second
        servo_9.write(105);   // Reverse the turn
        delay(1000);         // Hold the reverse turn for 1 second
      }

      // After avoiding, reset the servo to default position
      servo_9.write(80);
    }



    } 
  }
  else{
      if(rightdist <= 30){
    servo_9.write(105);
    delay(1000);
    servo_9.write(55);
    delay(500);
  }

  if(leftdist <= 30){
      servo_9.write(55);
      delay(1000);
      servo_9.write(105);
      delay(500);
      }

      servo_9.write(80);
      delay(500);
  }
  // Short delay before the next loop iteration
  delay(100);  
}

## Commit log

2024-11-06 Create ArduinoLibraries
2024-11-06 Create ArduinoLibraires
2024-11-14 Create circuit
